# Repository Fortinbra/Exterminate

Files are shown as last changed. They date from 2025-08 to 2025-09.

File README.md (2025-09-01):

# Exterminate

> **✅ Development Status**
> 
> This project has been tested on physical hardware (Pimoroni Pico LiPo 2 XL W) and verified to run core features including Bluetooth gamepad control, differential drive movement, and I2S audio playback. The codebase was developed with assistance from GitHub Copilot and refined through hands-on testing by the author and contributors.
> 
> **Key Dependencies**: Built upon [BluePad32](https://github.com/ricardoquesada/bluepad32) for Bluetooth gamepad support and [rp2040_i2s_example](https://github.com/malacalypse/rp2040_i2s_example) for PIO-based I2S audio implementation.
> 
> **Notes**: While the project is tested and functioning, additional edge cases and hardware revisions may surface further issues. Contributions, bug reports, and validation against different hardware revisions are welcome.

A C++ project for the Pimoroni Pico LiPo 2 XL W that brings an animatronic Dalek to life with Bluetooth gamepad control, differential drive movement, and iconic audio playback.

## 🤖 Project Overview

Exterminate is a Dalek control system that enables wireless gamepad control of a mobile Dalek replica. The project features differential drive movement and I2S audio playback for the iconic "Exterminate!" sound effects. It demonstrates modern C++ best practices, clean architecture, and SOLID principles while interfacing with embedded hardware.

> **Note**: This is an educational project created for learning purposes. The "Dalek" name and associated content are the intellectual property of the BBC. See the [Copyright Disclaimer](#️-copyright-disclaimer) section for full details.

### Key Features

- **Bluetooth Gamepad Support**: Uses BluePad32 library for wireless controller connectivity with visual status indication
- **Differential Drive Control**: Sophisticated two-wheel movement with forward/reverse and turning
- **Pimoroni Motor SHIM for Pico (DRV8833-based)**: Motor SHIM breakout providing a DRV8833 dual H-bridge with convenient headers and power wiring (see [Pimoroni Motor SHIM for Pico](https://shop.pimoroni.com/products/motor-shim-for-pico))
- **PIO-Based I2S Audio**: High-quality 44.1kHz PCM audio output using pico-extras I2S library
- **Audio-Reactive LEDs**: Real-time LED visualization that pulses with audio intensity for authentic Dalek head lighting
- **Controller Status LED**: Visual feedback showing controller connection status (solid when paired, flashing when waiting)
- **Modern C++17**: Clean, maintainable code following SOLID principles and RAII patterns
- **Hardware Abstraction**: Modular design allowing easy hardware component swapping

## 🛠️ Hardware Requirements

### Core Components

- **Pimoroni Pico LiPo 2 XL W** (RP2350-based board; this is the board used for testing)
- **Pimoroni Motor SHIM for Pico** (DRV8833-based dual H-bridge for differential drive movement). See: [Pimoroni Motor SHIM for Pico](https://shop.pimoroni.com/products/motor-shim-for-pico)
- **Two DC Motors** (geared motors recommended for mobile Dalek base)
- **I2S Audio Amplifier** (Adafruit MAX98357A I2S amplifier breakout — see [Adafruit MAX98357A Breakout (Product 3006)](https://www.adafruit.com/product/3006))
- **PWM-Compatible LEDs** (4x LEDs for audio visualization, 1x LED for controller status)
- **Speaker** (4-8Ω speaker, 3W recommended for MAX98357A)
- **Bluetooth Gamepad** (PS3, PS4, Xbox, or compatible controller)

### Wiring Diagram

```text
Pico W -> Pimoroni Motor SHIM (Movement)
GPIO 6 -> AIN1 (Left Motor Direction 1)
GPIO 7 -> AIN2 (Left Motor Direction 2)
GPIO 27 -> BIN1 (Right Motor Direction 1)
GPIO 26 -> BIN2 (Right Motor Direction 2)
3V3    -> VCC
GND    -> GND

Motor SHIM (DRV8833) -> Motors
AOUT1/AOUT2 -> Left Motor
BOUT1/BOUT2 -> Right Motor

Pico W -> I2S Audio Amplifier (PIO-based)
-----------------------------
GPIO 32 -> I2S BCLK (Bit Clock)
GPIO 33 -> I2S LRCLK (Left/Right Clock)
GPIO 34 -> I2S DOUT (Data Output)
5V      -> VIN (Power Input)
GND     -> GND

I2S Amplifier -> Speaker
------------------------
Speaker+ -> Speaker Positive Terminal
Speaker- -> Speaker Negative Terminal

Pico W -> Audio Visualization LEDs
----------------------------------
GPIO 13 -> External Red LED 1 (PWM for intensity control)
GPIO 14 -> External Red LED 2 (PWM for intensity control)
GND     -> LED Cathodes (via current limiting resistors)

Pico W -> Controller Status LED (Eye Stalk)
-------------------------------
GPIO 44 -> Blue eye LED (Status: BREATHING = pairing, SOLID = paired, FAST BLINK = error)
GND     -> LED Cathode (via current limiting resistor)

I2S Amplifier -> Speaker
------------------------
Speaker+ -> Speaker Positive Terminal
Speaker- -> Speaker Negative Terminal
```

## 🚀 Quick Start

### Prerequisites

1. **Pico SDK v2.1.1** installed and configured
2. **CMake 3.13+** and **Ninja** build system
3. **ARM GCC Toolchain** for cross-compilation
4. **Git** with submodule support

### Building the Project

1. **Clone the repository**:

   ```bash
   git clone --recursive https://github.com/yourusername/Exterminate.git
   cd Exterminate
   ```

2. **Initialize submodules** (if not cloned with `--recursive`):

   ```bash
   git submodule update --init --recursive
   ```

3. **Configure the build**:

   ```bash
   mkdir build
   cd build
   cmake .. -G Ninja
   ```
   - Copy `build/Exterminate.uf2` to the mounted drive
   - Or use: `picotool load Exterminate.uf2 -fx`

## 🎮 Usage

### Gamepad Pairing

1. **Put Pico W in pairing mode**: The system automatically enters pairing mode on startup
2. **Pair your gamepad**: Follow standard Bluetooth pairing procedure for your controller
3. **Verify connection**: Controller status LED on GPIO 15 will show solid light when connected, flashing when waiting for pairing

### Controls

- **Left Joystick Y-Axis**: Forward/Backward movement
- **Left Joystick X-Axis**: Steering (differential drive)
- **Right Trigger/Button**: Play "Exterminate!" audio
- **Face Buttons**: Additional sound effects (if implemented)
- **Deadzone**: 10% deadzone prevents drift from centered joysticks

```text
Movement:     Left stick Y -> Forward/Backward drive
Steering:     Left stick X -> Differential turning
Audio Trigger: Right trigger -> "Exterminate!" sound effect
```

## 🏗️ Project Structure

```text
Exterminate/
├── .github/
│   └── copilot-instructions.md    # Coding guidelines and best practices
├── include/                       # Public header files
│   ├── exterminate_platform.h     # Platform interface declarations
│   ├── MotorController.h          # Motor driver class interface
│   ├── AudioController.h          # Audio controller class interface
│   ├── SimpleLED.h                # Minimal LED helper (PWM)
│   ├── I2S.h                      # PIO-based I2S audio interface
│   └── audio/                     # Generated audio headers (from MP3s)
│       ├── 00001.h                # "Exterminate!" audio data
│       ├── 00002.h                # Additional sound effects
│       ├── ...                    # More audio files
│       └── audio_index.h          # Audio file registry
├── src/                          # Source implementation files
│   ├── main.cpp                  # Application entry point
│   ├── exterminate_platform.cpp  # BluePad32 platform implementation
│   ├── MotorController.cpp       # Motor control implementation
│   ├── AudioController.cpp       # Audio control implementation
│   ├── SimpleLED.cpp             # Minimal LED helper implementation
│   ├── I2S.cpp                   # PIO-based I2S implementation
│   ├── i2s.pio                   # PIO assembly for I2S state machines
│   ├── btstack_config.h          # BTstack configuration
│   └── sdkconfig.h               # BluePad32 configuration
├── lib/                          # External libraries
│   └── bluepad32/                # BluePad32 submodule
├── misc/                         # Audio source files (excluded from git)
│   ├── 00001.mp3                # "Exterminate!" audio sample (source)
│   ├── 00002.mp3                # Additional Dalek sound effects (source)
│   └── ...                      # More audio samples (source)
├── tools/                        # Build and conversion tools
│   ├── mp3_to_header.py         # MP3 to C++ header converter
│   ├── convert_audio.ps1        # PowerShell conversion script
│   └── convert_audio.bat        # Batch conversion script
├── docs/                         # Project & build documentation
│   ├── audio_system.md          # Audio system documentation
│   └── build/                   # Build + assembly guides (see README there)
├── tests/                        # Unit tests (future)
├── build/                        # Build output (generated)
├── CMakeLists.txt               # Build system configuration
├── COPYRIGHT.md                 # Copyright and IP information
└── README.md                    # This file
```

## 🧩 Architecture

### Design Principles

The project follows **SOLID principles** and modern C++ best practices:

- **Single Responsibility**: Each class has one clear purpose
- **Open/Closed**: Extensible design through interfaces
- **Liskov Substitution**: Proper inheritance hierarchies
- **Interface Segregation**: Small, focused interfaces
- **Dependency Inversion**: Abstractions over implementations

### Key Classes

#### `MotorController`

- **Purpose**: Hardware abstraction for DRV8833-based motor driver
- **Features**: PWM speed control, differential drive algorithms, RAII resource management
- **Interface**: `setMotorSpeed()`, `setDifferentialDrive()`, `stopAllMotors()`

#### `AudioController`

- **Purpose**: Pico-extras I2S audio output with LED integration
- **Features**: 44.1kHz PCM audio playback, real-time audio intensity calculation, LED synchronization, resource discovery pattern
- **Interface**: `playAudio()`, `stopAudio()`, `getAudioIntensity()`, `initialize()` methods

#### `SimpleLED`

- **Purpose**: Lightweight PWM helper for external LEDs
- **Features**: Pin init, PWM init, and brightness setting; audio-driven updates done in `main.cpp`
- **Interface**: `initializePwmPin()`, `setBrightnessPin()`

#### `exterminate_platform`

- **Purpose**: BluePad32 platform integration with controller status indication
- **Features**: Gamepad event handling, joystick normalization, audio triggers, controller status LED management
- **Interface**: Standard BluePad32 platform callbacks with LED status integration

### Data Flow

```text
Gamepad Input → BluePad32 → Platform Handler → Motor Controller → Drive Motors (Movement)
                                            └→ Audio Controller → Pico-Extras I2S → Speaker
                                            └→ LED Controller → PWM LEDs → Audio Visualization
                                            └→ Status LED → Controller Connection Feedback
```

## ⚙️ Configuration

### Motor Controller Settings

Edit the configuration in `src/exterminate_platform.cpp`:

```cpp
// Current MotorController configuration for movement
MotorController::Config motorConfig = {
    .leftMotorPin1 = 2,   // GPIO pins for DRV8833
    .leftMotorPin2 = 3,
    .rightMotorPin1 = 4,
    .rightMotorPin2 = 5,
    .pwmFrequency = 10000 // 10kHz PWM frequency
};

// AudioController configuration for sound effects
AudioController::Config audioConfig = {
    .bclkPin = 6,              // I2S bit clock (PIO-based)
    .lrclkPin = 8,             // I2S left/right clock
    .dinPin = 9,               // I2S data input
    .sampleRate = 22050,       // 22.05kHz audio
    .bitsPerSample = 16        // 16-bit PCM audio
};

// SimpleLED setup for audio visualization (example)
Exterminate::SimpleLED::initializePwmPin(11, 255, 4.0f);
Exterminate::SimpleLED::initializePwmPin(12, 255, 4.0f);

// Controller status LED configuration
const uint controllerStatusPin = 15;  // GPIO 15 for status indication
```

### Audio File Conversion

The project uses embedded audio files converted from MP3s:

> **Copyright Notice**: Users are responsible for ensuring they have appropriate rights to any audio files used. This project does not include copyrighted Dalek audio content - it only provides the technical framework for audio playback.

```bash
# Convert MP3 files to C++ headers (Windows)
.\tools\convert_audio.ps1

# Or use batch file
tools\convert_audio.bat

# Manual conversion
python tools\mp3_to_header.py misc include\audio
```

**Audio Usage:**

```cpp
#include "AudioController.h"
#include "audio/audio_index.h"

// Play "Exterminate!" sound
audioController.playAudio(Audio::AudioIndex::AUDIO_00001);
```

### Deadzone and Sensitivity

Adjust gamepad sensitivity for movement and eye stalk control in `exterminate_platform_on_controller_data()`:

```cpp
const float DEADZONE = 0.1f;  // 10% deadzone for both movement and eye stalk
// Modify as needed for smooth operation of both drive and eye stalk
```

## 🔧 Development

### Code Style

The project uses **clang-format** for consistent code formatting. Key conventions:

- **Classes**: `PascalCase`
- **Functions/Variables**: `camelCase`  
- **Constants**: `UPPER_CASE_SNAKE_CASE`
- **Namespaces**: `Exterminate`
- **Headers**: `#pragma once`

### Building for Development

Enable debug output and additional logging:

```bash
cmake .. -DCMAKE_BUILD_TYPE=Debug
```

### Testing

While embedded testing is complex, the modular design supports unit testing:

- Hardware interfaces are abstracted
- Business logic is separated from hardware specifics
- Mock implementations can be provided for testing

## 🐛 Troubleshooting

### Common Issues

1. **Build Failures**:
   - Ensure Pico SDK v2.1.1 is properly installed
   - Check CMake and Ninja versions
   - Verify git submodules are initialized

1. **Gamepad Not Connecting**:
   - Check gamepad compatibility with BluePad32
   - Verify Bluetooth functionality on Pico W
   - Try resetting gamepad to pairing mode

1. **Motors Not Responding**:
   - Check wiring connections to DRV8833
   - Verify power supply to motor driver
   - Test PWM output with oscilloscope/logic analyzer

1. **No Audio Output**:
   - Check I2S amplifier wiring and connections
   - Verify MAX98357A power supply (5V required)
   - Ensure speaker impedance is 4-8Ω
   - Check SD pin is tied to 3V3 (shutdown control)
   - Test I2S signals with oscilloscope or logic analyzer

1. **Compilation Errors**:
   - Ensure C++17 standard is enabled
   - Check include paths for BluePad32
   - Verify btstack configuration files

1. **DMA Channel Conflicts** (Critical Fix Applied):
   - **Symptoms**: Runtime panic "DMA channel X is already claimed", LED staying solid, gamepad not pairing
   - **Root Cause**: Pico-extras I2S library expects to manage its own resources internally
   - **Solution**: Resource discovery pattern implemented in AudioController::initialize()
   - **Reference**: See `docs/troubleshooting_dma_conflicts.md` for detailed explanation

### Debug Output

Enable USB serial output for debugging:

```cpp
// In CMakeLists.txt (already configured)
pico_enable_stdio_usb(Exterminate 1)
```

Monitor output:

```bash
# Windows
# Use PuTTY or similar terminal emulator

# Linux/macOS  
screen /dev/ttyACM0 115200
```

## 📚 Dependencies

### Core Libraries

- **Pico SDK v2.1.1**: Raspberry Pi Pico development framework
- **BluePad32**: Bluetooth gamepad support library ([GitHub](https://github.com/ricardoquesada/bluepad32))
- **BTstack**: Bluetooth protocol stack
- **CYW43**: WiFi/Bluetooth driver for Pico W

### Hardware Libraries

-- **hardware_pwm**: PWM generation for motor control
- **hardware_i2s**: I2S audio output with MAX98357A amplifier
- **hardware_gpio**: GPIO pin control and configuration
- **pico_stdlib**: Standard Pico functionality

### Key Inspirations and References

- **I2S Implementation**: Based on [malacalypse/rp2040_i2s_example](https://github.com/malacalypse/rp2040_i2s_example) - Excellent reference for PIO-based I2S audio output
- **BluePad32 Integration**: Comprehensive Bluetooth gamepad library by Ricardo Quesada
- **Printables Animated Dalek (Rick100)**: This project was inspired by and is a remix of Rick100's "Animated Dalek with Sound" model on Printables — [Animated Dalek with Sound](https://www.printables.com/model/1351261-animated-dalek-with-sound) (credit: Rick100)

## 🤝 Contributing

**Hardware Testing Needed!** This project is currently awaiting hardware validation. If you build and test this system, your feedback is invaluable!

### Priority Contributions

1. **Hardware Testing Reports**: Document what works, what doesn't, and any required modifications
2. **Bug Fixes**: Issues discovered during real-world testing
3. **Performance Optimizations**: Improvements based on actual hardware behavior
4. **Documentation Updates**: Corrections or additions based on practical experience

### Standard Contribution Process

1. **Fork the repository**
2. **Create a feature branch**: `git checkout -b feature/amazing-feature`
3. **Follow coding guidelines**: See `.github/copilot-instructions.md`
4. **Write tests** for new functionality
5. **Commit changes**: `git commit -m 'Add amazing feature'`
6. **Push to branch**: `git push origin feature/amazing-feature`
7. **Open a Pull Request**

### Code Review Checklist

- [ ] Follows SOLID principles
- [ ] Includes proper error handling
- [ ] Uses RAII for resource management
- [ ] Maintains consistent code style
- [ ] Includes appropriate documentation

## 📄 License

This project is licensed under the MIT License - see the [LICENSE](LICENSE) file for details.

## ⚠️ Copyright Disclaimer

### Important Notice Regarding Intellectual Property

The "Dalek" name, character design, and associated audio content (including "Exterminate!" and other phrases) are the intellectual property of the BBC and are protected by copyright. This project uses these elements purely for:

- **Educational purposes** - Teaching embedded systems programming and robotics
- **Entertainment and hobbyist use** - Personal projects and learning experiences
- **Non-commercial applications** - Not intended for sale or commercial distribution

**No Copyright Infringement Intended**: This project is a fan-made educational tool created out of appreciation for the Doctor Who series. All rights to the Dalek character, design, and audio remain with the BBC and the estate of Terry Nation.

**Audio Content**: Users are responsible for ensuring they have appropriate rights to any audio files they use with this system. The project provides tools for audio conversion but does not include copyrighted audio content.

**For Educational Use**: This project is intended to help students and hobbyists learn about:

- Embedded C++ programming
- Real-time audio processing
- Robotics and motor control
- Bluetooth communication protocols
- Hardware interfacing and design

If you are affiliated with the BBC or hold rights to the Dalek intellectual property and have concerns about this project, please contact the repository maintainer.

**For detailed copyright information, see [COPYRIGHT.md](COPYRIGHT.md).**

## 🎯 Future Enhancements

### Planned Features

- **Multiple Audio Samples**: Expand library of Dalek sound effects and phrases
- **Voice Modulation**: Real-time voice processing to sound like a Dalek
-- **Eye Stalk Lighting**: LED control for head illumination effects
- **Motion Sensors**: Trigger audio/movement based on proximity detection
- **Remote Web Interface**: Control Dalek via web browser for demonstrations

-### Hardware Expansions

- **LED Matrix/Displays**: Add visual effects and status indicators
-- **Proximity Sensors**: Automatic target detection and response
-- **Camera Module**: First-person view from the Dalek's perspective
-- **Voice Recognition**: Respond to specific voice commands
- **LED Matrix/Displays**: Add visual effects and status indicators
- **Proximity Sensors**: Automatic target detection and response
- **Camera Module**: First-person view from the Dalek's perspective
- **Voice Recognition**: Respond to specific voice commands

## 📞 Support

- **Issues**: Report bugs via GitHub Issues
- **Discussions**: Join project discussions  
- **Documentation**: Additional docs in `docs/` directory
- **Community**: BluePad32, Raspberry Pi Pico, and animatronics communities

---

Built with ❤️ for the Dalek and animatronics community

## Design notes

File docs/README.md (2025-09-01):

# Documentation Index

## Welcome to Exterminate Dalek Documentation

This documentation provides comprehensive information for building, programming, and operating an animatronic Dalek using the Raspberry Pi Pico W platform.

## Quick Navigation

### 🚀 New to the Project?

**[Getting Started Guide](getting_started.md)** - Start here for your first build

- Complete hardware shopping list
- 30-minute quick start tutorial  
- Basic assembly instructions
- Initial testing and troubleshooting

### 🏗️ System Documentation

**[System Architecture](system_architecture.md)** - High-level project overview

- Complete system design and component relationships
- Real-time constraints and performance requirements
- Error handling strategies and safety systems
- Memory management and resource allocation

**[Hardware Configuration](hardware_configuration.md)** - Complete wiring guide

- Pin assignments and GPIO allocations
- Component wiring diagrams with part numbers
- Power distribution and electrical requirements
- Assembly guidelines and mounting specifications

### 🎮 Control Systems

**[Gamepad Control](gamepad_control.md)** - Bluetooth controller integration

- Supported gamepad types (PS4/PS5, Xbox, Nintendo Switch)
- Pairing procedures and connection troubleshooting
- Control mapping and customization options
- Safety features and emergency stop functionality

**[Motor Control](motor_control.md)** - Movement system

- Pimoroni Motor Shim integration and configuration
- Differential drive mathematics and implementation

- PWM signal generation and timing requirements

### 🔊 Audio & Visual Systems

**[Audio System](audio_system.md)** - PIO-based I2S audio implementation

- PIO-based I2S audio generation architecture
- MAX98357A I2S amplifier integration and configuration
- Audio buffer management and real-time constraints
- LED integration for audio-reactive visual effects

**[Embedded Audio Usage](embedded_audio_usage.md)** - Audio file management

- MP3 to header file conversion process
- Audio file organization and naming conventions
- Build system integration for audio resources
- Runtime audio playback and control

**[LED System](led_system.md)** - Audio visualization and status indication

- Audio-reactive LED controller for Dalek head lighting effects
- Controller status LED for connection feedback
- PWM-based intensity control and effect patterns
- Hardware configuration and wiring specifications

### 🛠️ Development

**[Development Guide](development_guide.md)** - Complete development workflow

- Development environment setup and configuration
- Build system usage (CMake, Ninja, VS Code)
- Debugging techniques and profiling tools
- Testing strategies and continuous integration

**[Troubleshooting: DMA Conflicts](troubleshooting_dma_conflicts.md)** - Critical system fixes

- Resolution for "DMA channel already claimed" runtime panics
- LED staying solid and gamepad pairing issues  
- Resource discovery pattern implementation
- Prevention strategies for library integration conflicts

## Documentation Structure

### By Experience Level

**Beginner (First Time Building):**
1. [Getting Started Guide](getting_started.md) - Essential first steps
2. [Hardware Configuration](hardware_configuration.md) - Basic wiring
3. [Development Guide](development_guide.md) - Software setup

**Intermediate (Modifying and Extending):**
1. [System Architecture](system_architecture.md) - Understanding design
2. [Motor Control](motor_control.md) - Movement customization
3. [Audio System](audio_system.md) - Sound effect integration

**Advanced (Core Development):**
1. [Development Guide](development_guide.md) - Full development workflow
2. [System Architecture](system_architecture.md) - Design patterns
3. All module-specific documentation for deep implementation details

### By System Component

**Movement System:**
- [Motor Control](motor_control.md) - Pimoroni Motor Shim integration
- [Hardware Configuration](hardware_configuration.md) - Wiring details
- [Gamepad Control](gamepad_control.md) - Input handling

**Audio System:**
- [Audio System](audio_system.md) - I2S implementation  
- [Embedded Audio Usage](embedded_audio_usage.md) - File management
- [Hardware Configuration](hardware_configuration.md) - DAC wiring

**Control System:**
- [Gamepad Control](gamepad_control.md) - BluePad32 integration
- [System Architecture](system_architecture.md) - Control flow
- [Development Guide](development_guide.md) - Debugging controls

**Development Workflow:**
- [Development Guide](development_guide.md) - Complete workflow
- [Getting Started Guide](getting_started.md) - Initial setup
- [System Architecture](system_architecture.md) - Design understanding

## Project Features

### Hardware Capabilities

### Software Architecture

- **Real-Time Control**: 1ms motor control loop with safety monitoring
- **Concurrent Audio**: Independent I2S audio generation using PIO
- **Event-Driven Input**: BluePad32 gamepad event processing
- **Resource Management**: RAII-based hardware resource management
- **Safety Systems**: Emergency stop and fault detection throughout

### Development Tools

- **IDE Integration**: Full VS Code support with IntelliSense and debugging
- **Build System**: CMake with Ninja for fast compilation
- **Audio Pipeline**: Automated MP3 to C header conversion
- **Testing Framework**: Unit testing with hardware abstraction
- **Documentation**: Comprehensive guides with code examples

## File Organization

### Source Code Structure

```
src/
├── main.cpp                 # Main application entry point
├── AudioController.cpp      # I2S audio system implementation  
├── MotorController.cpp      # Motor control
├── exterminate_platform.cpp # BluePad32 platform integration
├── btstack_config.h         # Bluetooth stack configuration
└── sdkconfig.h             # SDK configuration options
```

### Header Files

```
include/
├── AudioController.h        # Audio system interface
├── MotorController.h        # Motor control interface
├── exterminate_platform.h  # Platform definitions
└── audio/                  # Generated audio headers (24 files)
    ├── audio_index.h       # Audio file index and metadata
    ├── 00001.h → 00024.h   # Individual audio file data
    └── ...
```

### Documentation Files

```
docs/
├── README.md               # This index file
├── getting_started.md      # New user tutorial
├── system_architecture.md  # High-level system design
├── hardware_configuration.md # Complete wiring guide
├── motor_control.md        # Movement system details
├── gamepad_control.md      # Input system documentation
├── audio_system.md         # I2S audio implementation
├── embedded_audio_usage.md # Audio file management
└── development_guide.md    # Complete development workflow
```

### Build and Tools

```
tools/
├── mp3_to_header.py        # Audio conversion script
├── convert_audio.ps1       # PowerShell automation
└── convert_audio.bat       # Windows batch automation

CMakeLists.txt              # Main build configuration
pico_sdk_import.cmake       # Pico SDK integration
.clang-format              # Code style configuration
```

## Getting Help

### Common Questions

**Q: Where do I start if I'm new to embedded development?**

A: Begin with the [Getting Started Guide](getting_started.md). It walks through everything from buying components to your first successful build.

**Q: How do I add my own sound effects?**

A: See [Embedded Audio Usage](embedded_audio_usage.md) for the complete process of converting MP3 files and integrating them into the build.

**Q: My motors aren't working correctly. What should I check?**

A: The [Motor Control](motor_control.md) documentation has a comprehensive troubleshooting section covering wiring, power, and software issues.

**Q: Can I use a different gamepad than the ones mentioned?**

A: The [Gamepad Control](gamepad_control.md) guide covers all supported controllers and includes information about compatibility with other Bluetooth gamepads.

**Q: How do I modify the code for my specific needs?**

A: Start with [System Architecture](system_architecture.md) to understand the overall design, then refer to the [Development Guide](development_guide.md) for the development workflow.

### Troubleshooting Resources

1. **Build Issues**: [Development Guide - Troubleshooting](development_guide.md#troubleshooting)
2. **Hardware Problems**: [Hardware Configuration - Safety](hardware_configuration.md#safety-considerations)  
3. **Audio Problems**: [Audio System - Troubleshooting](audio_system.md#troubleshooting)
4. **Motor Issues**: [Motor Control - Troubleshooting](motor_control.md#troubleshooting)
5. **Control Issues**: [Gamepad Control - Troubleshooting](gamepad_control.md#troubleshooting)

### Community and Support

- **Project Repository**: [GitHub Repository](https://github.com/your-username/Exterminate)
- **Issue Tracking**: Use GitHub Issues for bug reports and feature requests
- **Discussions**: GitHub Discussions for questions and community support
- **Wiki**: Additional community-contributed documentation and examples

## Version Information

**Documentation Version**: 1.0  
**Project Version**: See `CMakeLists.txt` for current version  
**Last Updated**: January 2025  
**Pico SDK Version**: 2.0+  
**BluePad32 Version**: Latest from submodule  

## Contributing to Documentation

We welcome improvements to the documentation! Here's how to contribute:

1. **Small Fixes**: Edit files directly and submit a pull request
2. **Major Changes**: Open an issue first to discuss the proposed changes
3. **New Sections**: Follow the existing documentation structure and style
4. **Code Examples**: Test all code examples before submitting

**Documentation Standards**:
- Use clear, concise language suitable for beginners
- Include practical examples and code snippets
- Provide troubleshooting information for common issues
- Cross-reference related documentation sections
- Follow markdown formatting guidelines

---

**Ready to Build Your Dalek?**

Start with the [Getting Started Guide](getting_started.md) and begin your journey into embedded robotics!

For quick reference, bookmark this index page and the documentation section most relevant to your current development phase.

**EXTERMINATE... with proper documentation!** 🤖📚

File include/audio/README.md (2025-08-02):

# Audio System README

## Overview

The Exterminate Dalek project uses a preprocessed audio system for GitHub Actions compatibility. Audio files are converted from MP3 to PCM format during development and the generated header files are committed to the repository.

## Audio File Management

### Current Audio Library

The project contains **24 audio files** (00001.mp3 through 00024.mp3) converted to PCM format:

- **Format**: 22.05kHz, mono, 16-bit PCM
- **Total Duration**: ~2.5 minutes of audio
- **Memory Usage**: ~6MB of embedded audio data
- **Files**: `include/audio/00001.h` through `include/audio/00024.h`
- **Index**: `include/audio/audio_index.h` (master audio file registry)

### Adding or Updating Audio Files

**For Development (Local Changes):**

1. **Install Dependencies** (one-time setup):
   ```bash
   pip install librosa soundfile numpy==2.1.0
   ```

2. **Add MP3 Files**:
   - Place MP3 files in `misc/` directory
   - Use numbered naming: `00001.mp3`, `00002.mp3`, etc.

3. **Convert to PCM Headers**:
   ```bash
   # PowerShell
   .\tools\convert_audio.ps1
   
   # Command Prompt
   tools\convert_audio.bat
   
   # Python directly
   python tools/audio_to_pcm_header.py misc include/audio --pattern "*.mp3"
   ```

4. **Commit Generated Headers**:
   ```bash
   git add include/audio/*.h
   git commit -m "Update audio files"
   ```

**For GitHub Actions (CI/CD):**

- ✅ **No audio dependencies needed** - Header files are pre-generated
- ✅ **Fast builds** - No MP3 processing during CI
- ✅ **Reliable** - No dependency on external audio libraries

### Audio File Structure

**Generated Header Format:**
```cpp
// Example: include/audio/00001.h
namespace Exterminate::Audio {
    extern const int16_t AUDIO_00001_DATA[];      // PCM sample data
    extern const size_t AUDIO_00001_SAMPLE_COUNT; // Number of samples
    extern const size_t AUDIO_00001_BYTE_SIZE;    // Total bytes
    extern const uint32_t AUDIO_00001_SAMPLE_RATE; // 22050 Hz
    extern const uint8_t AUDIO_00001_CHANNELS;    // 1 (mono)
    extern const uint8_t AUDIO_00001_BIT_DEPTH;   // 16 bits
}
```

**Master Index (`audio_index.h`):**
```cpp
// Audio file registry with helper functions
enum class AudioIndex : size_t {
    AUDIO_00001 = 0,
    AUDIO_00002 = 1,
    // ... all 24 files
    COUNT = 24
};

const AudioFile* getAudioFile(AudioIndex index);
const AudioFile* getAudioFile(const char* name);
```

### Usage in Code

**Playing Audio Files:**
```cpp
#include "audio/audio_index.h"
using namespace Exterminate::Audio;

// Method 1: By index
auto audioFile = getAudioFile(AudioIndex::AUDIO_00001);
audioController.playPCMAudioData(
    audioFile->data,
    audioFile->sample_count,
    audioFile->sample_rate,
    audioFile->channels
);

// Method 2: By name
auto audioFile = getAudioFile("00001.mp3");
if (audioFile) {
    audioController.playAudio(AudioIndex::AUDIO_00001);
}
```

**Checking Available Audio:**
```cpp
// Get total number of audio files
size_t totalFiles = static_cast<size_t>(AudioIndex::COUNT); // 24

// List all available files
for (size_t i = 0; i < AUDIO_FILE_COUNT; ++i) {
    printf("Audio file %zu: %s (%.2f seconds)\n", 
           i, 
           AUDIO_FILES[i].name,
           (float)AUDIO_FILES[i].sample_count / AUDIO_FILES[i].sample_rate);
}
```

## Memory Usage

**Total Audio Memory**: ~6MB (embedded in flash)

**Per-File Breakdown:**
- **Shortest**: 00001.mp3 (1.4s, 61KB)
- **Longest**: 00022.mp3 (23.0s, 1MB)
- **Average**: ~250KB per file

**Memory Optimization:**
- Files are stored in flash memory (not RAM)
- PCM data is accessed directly (no copying)
- Mono format saves 50% vs stereo
- 22.05kHz sample rate balances quality/size

## Technical Details

**PCM Format Advantages:**
- ✅ **No CPU overhead** - Direct I2S output
- ✅ **Predictable timing** - No decoding delays
- ✅ **High quality** - No compression artifacts
- ✅ **Deterministic** - Perfect for real-time systems

**Build Integration:**
- Audio headers are automatically included in CMake build
- No additional build steps required
- Compatible with all Pico SDK versions
- Works with VS Code and command-line builds

**GitHub Actions Compatibility:**
- Pre-generated headers eliminate Python dependencies
- Fast CI builds (no audio processing)
- Deterministic builds across all platforms
- No external library requirements

## File Locations

```
Exterminate/
├── misc/                    # MP3 source files (not in git)
│   ├── 00001.mp3           # Original audio files
│   └── ...                 # (excluded by .gitignore)
├── include/audio/          # Generated PCM headers (in git)
│   ├── 00001.h            # PCM data for each file
│   ├── ...                # All 24 audio files
│   └── audio_index.h      # Master registry
└── tools/                  # Conversion tools
    ├── audio_to_pcm_header.py  # Main conversion script
    ├── convert_audio.ps1   # PowerShell wrapper
    └── convert_audio.bat   # Batch wrapper
```

## Troubleshooting

**Build Errors:**
- Ensure all `.h` files are committed to git
- Check that `audio_index.h` includes all files
- Verify PCM format consistency across files

**Audio Quality Issues:**
- Original MP3 quality affects PCM output
- Consider higher sample rates for critical audio
- Check for clipping in conversion process

**Memory Issues:**
- Monitor total flash usage with large audio sets
- Consider shorter clips or lower sample rates
- Use compression-friendly original formats

**Development Workflow:**
- Always test converted audio before committing
- Keep MP3 sources backed up separately
- Document audio file purposes in code comments

## Future Enhancements

**Potential Improvements:**
- Dynamic loading for larger audio libraries
- Compression-optimized PCM formats
- Multi-sample rate support
- Background audio streaming
- Audio effects processing

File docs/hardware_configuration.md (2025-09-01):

# Hardware Configuration Guide

## Overview

This guide covers the complete hardware setup for the Exterminate Dalek project, including pin assignments, wiring diagrams, and component specifications.

## Core Hardware

### Raspberry Pi Pico W

The Raspberry Pi Pico W serves as the main microcontroller with built-in WiFi and Bluetooth capabilities.

**Key Features:**
- **CPU**: Dual-core ARM Cortex-M0+ @ 133MHz
- **Memory**: 264KB SRAM, 2MB Flash
- **I/O**: 26 GPIO pins, 3 ADC inputs
- **Connectivity**: 802.11n WiFi, Bluetooth 5.2
- **Power**: 1.8-5.5V input, 3.3V logic levels

### Board Pinout: Pico LiPo 2 XL W

The project uses the Pico LiPo 2 XL W form-factor board. Refer to the following pinout diagram when wiring peripherals and mapping GPIOs:

Pico LiPo 2 XL W Pinout Diagram

#### Notes

- The GPIO numbering in this documentation refers to the RP2350/RP2040 GPIO numbers shown on the diagram.
- Physical pad locations differ from the standard Raspberry Pi Pico; double‑check the board silkscreen when wiring.
- Power rails and special pins (VBUS, VSYS, 3V3, GND) are labeled on the diagram; ensure polarity and voltage limits are respected.

## Pin Assignment Map

### GPIO Pin Allocations

| GPIO | Function | Component | Direction | Notes |
|---|---|---|---|---|
| **0** | UART TX | Debug Console | Output | USB Serial |
| **1** | UART RX | Debug Console | Input | USB Serial |
| **2** | *Reserved* | Future Expansion | - | Available |
| **3** | *Reserved* | Future Expansion | - | Available |
| **4** | *Reserved* | Future Expansion | - | Available |
| **5** | *Reserved* | Future Expansion | - | Available |
| **6** | AIN1 | Left Motor Pin 1 (Motor Shim) | Output | PWM Control |
| **7** | AIN2 | Left Motor Pin 2 (Motor Shim) | Output | PWM Control |
| **6** | *Reserved* | Future Expansion | - | Available |
| **7** | *Reserved* | Future Expansion | - | Available |
| **8** | *Reserved* | Future Expansion | - | Available |
| **9** | *Reserved* | Future Expansion | - | Available |
| **10** | *Reserved* | Future Expansion | - | Available |
| **11** | LED PWM | Dome Red LED 1 (Audio Viz) | Output | PWM Control |
| **12** | LED PWM | Dome Red LED 2 (Audio Viz) | Output | PWM Control |
| **13** | *Reserved* | Future Expansion | - | Available |
| **14** | *Reserved* | Future Expansion | - | Available |
| **15** | Blue Status LED | Eye Stalk Bluetooth Status | Output | Digital Control |
| **16** | *Reserved* | Future expansion | - | - |
| **17-25** | *Reserved* | Future Expansion | - | Available |
| **26** | BIN2 | Right Motor Pin 2 (Motor Shim) | Output | PWM Control |
| **27** | BIN1 | Right Motor Pin 1 (Motor Shim) | Output | PWM Control |
| **28-31** | *Reserved* | Future Expansion | - | Available |
| **32** | I2S BCLK | Audio Bit Clock | Output | PIO I2S |
| **33** | I2S LRCLK | Audio Word Select | Output | PIO I2S |
| **34** | I2S DIN | Audio Data Out | Output | PIO I2S |
| **35** | *Reserved* | Future Expansion | - | Available |

### Power Pins

| Pin | Function | Voltage | Current |
|-----|---|---|---|
| **VSYS** | System Power In | 1.8-5.5V | 500mA max |
| **VBUS** | USB Power In | 5V | 500mA max |
| **3V3** | 3.3V Power Out | 3.3V | 300mA max |
| **GND** | Ground | 0V | - |

## Component Wiring

### Pimoroni Motor Shim for Pico

The Pimoroni Motor Shim stacks directly onto the Pico LiPo 2 XL W board. Motor power and connections are handled by the shim.

**GPIO Mapping:**

```text
Pico GPIO   Motor Shim   Function
---------   ----------   -------------------------------
GPIO 6      AIN1         Left motor direction 1 (PWM)
GPIO 7      AIN2         Left motor direction 2 (PWM)
GPIO 27     BIN1         Right motor direction 1 (PWM)
GPIO 26     BIN2         Right motor direction 2 (PWM)
```

**Power & Motors:**

```text
Motor Shim   Function
----------   -----------------------------------------
VMOTOR       Motor supply input (per shim spec)
MOTOR A +/-  Left motor terminals (connect to motor)
MOTOR B +/-  Right motor terminals (connect to motor)
```

#### Notes

- The shim is soldered as a stack; no separate breadboard wiring for motor pins is required.
- Provide adequate motor supply per Pimoroni specs; do not power motors from Pico 3V3.
- Keep 20 kHz PWM to move switching out of audible range.

### I2S Audio Amplifier

**MAX98357A I2S Amplifier Module:** (Adafruit MAX98357A Breakout: [Adafruit product 3006](https://www.adafruit.com/product/3006))

```text
MAX98357A Pin Pico W      Function
------------- ------      --------
VIN      -->  5V          Power (5V from VSYS)
GND      -->  GND         Ground
BCLK     -->  GPIO 32     Bit Clock (I2S)
LRCLK    -->  GPIO 33     Left/Right Clock (I2S)
DIN      -->  GPIO 34     Data Input (I2S)
GAIN     -->  GND         Gain Setting (9dB when tied to GND)
SD       -->  3V3         Shutdown Control (3V3 = enabled)
```

**Speaker Connection:**

```text
Amplifier     Speaker
---------     -------
Speaker+ -->  Speaker Positive Terminal (4-8Ω, 3W max)
Speaker- -->  Speaker Negative Terminal
```

**MAX98357A Advantages:**

- **Integrated Solution**: DAC + Class D amplifier in one module
- **High Efficiency**: Class D amplifier design for low power consumption
- **Direct Speaker Drive**: No external amplifier required
- **I2S Interface**: Clean digital audio interface
- **Compact**: Small form factor suitable for embedded projects

### Audio Visualization LEDs (Dome, Red)

**LED Array for Dalek Head Lighting (2x Red):**

```text
LED Pin      Pico W      Function
-------      ------      --------
LED 1 +  --> GPIO 37     PWM Control (Audio Intensity)
LED 2 +  --> GPIO 38     PWM Control (Audio Intensity)
All -    --> GND         Common Ground
```

**LED Requirements and Resistors (3.3 V GPIO):**

- Dome LEDs (red): 150Ω recommended (≈7–9 mA each). Use 100Ω if higher brightness is needed (≈11–13 mA), staying within GPIO limits.

- One series resistor per LED.
- Red LED (Vf ≈ 2.0–2.2 V):
   - 150Ω → ~7–9 mA (recommended default)
   - 100Ω → ~11–13 mA (upper end of per‑pin drive)
- Blue LED (Vf ≈ 3.0–3.2 V):
   - 100–150Ω → ~1–3 mA (limited headroom at 3.3 V)
- For true ~20 mA brightness:
   - Red at 3.3 V: use a transistor/MOSFET driver and 62–68Ω.
   - Blue: use a 5 V LED supply with a driver and 100Ω (common ground with Pico).

**Effects:**

- Two red dome LEDs flash in sync with audio intensity via PWM to represent speech.

### Bluetooth Status LED (Eye Stalk, Blue)

**Wiring:**

```text
Eye Stalk LED   Pico W      Function
--------------  ------      --------
LED +       -->  GPIO 36     Digital Control (Status)
LED -       -->  GND         Ground (via series resistor: blue 100–150Ω)
```

**Status Patterns:**

- **Blinking**: Bluetooth pairing/connecting
- **Solid**: Bluetooth paired/connected

## Power Distribution

### Power Requirements

| Component | Voltage | Current | Power |
|---|---|---|---|
| Pico W | 3.3V | 150mA | 0.5W |
| Motor Shim Logic | 3.3V | 10mA | 0.03W |
| Motors (2x) | 5-6V | 1A each | 5-6W |
 
| Audio DAC | 3.3V | 50mA | 0.17W |
| **Total** | - | **~2.7A** | **~8.2W** |

### Recommended Power Supply

**For USB Development:**

- **USB Power**: 5V @ 500mA (limited)
- **Suitable for**: Testing, programming, light motors
- **Limitations**: May brownout with full motor load

**For Full Operation:**

- **External Supply**: 6V @ 3A minimum
- **Connection**: Via VSYS pin or external power distribution
- **Protection**: Fuse or current limiting recommended

### Power Distribution Schematic

```text
External 6V Supply
       |
    [FUSE]
       |
   +---+---+
   |       |
VSYS      Motor Shim VMOTOR
(Pico)    (Motor Power)
   |
   
```

## Assembly Guidelines

### PCB Layout Considerations

**Signal Routing:**

- Keep PWM traces short and direct
- Separate analog and digital grounds where possible
- Use ground planes for EMI reduction
- Route I2S signals with controlled impedance

**Power Routing:**

- Use thick traces for motor power (≥20 mil)
- Add bulk capacitance near motor driver input (100µF+ at VMOTOR)
- Decouple all IC power pins (0.1µF ceramic)
- Consider separate power planes for logic and motors

### Mechanical Mounting

**Pico W Mounting:**

- Use M2.5 standoffs to prevent board flex
- Ensure adequate ventilation around CYW43 chip
- Keep antenna area clear of metal objects

**Motor Mounting:**

- Secure motors to prevent vibration
- Use flexible wires to accommodate movement
- Add encoder feedback if precise positioning needed

## Development Setup

### Programming Interface

**Built-in USB:**

```text
Pico W USB-C --> Computer USB-A/C
```

**Debug Interface (Optional SWD):**

```text
Pico W      Debugger    Function
------      --------    --------
SWCLK  -->  SWCLK       SWD Clock
SWDIO  -->  SWDIO       SWD Data
GND    -->  GND         Ground
```

### Development Tools Required

**Hardware:**

- USB-C cable for programming
- Breadboard or PCB for prototyping
- Multimeter for debugging
- Oscilloscope (optional, for PWM verification)

**Software:**

- Pico SDK toolchain
- VS Code with Pico extension
- Ninja build system
- Serial terminal (minicom, PuTTY, etc.)

## Safety Considerations

### Electrical Safety

**Power Supply:**

- Never exceed 5.5V on VSYS pin
- Use current limiting to prevent overcurrent
- Add reverse polarity protection
- Ensure adequate heat dissipation

**Motor Safety:**

- Motors can generate back-EMF when stopped suddenly
- Motor driver includes protection diodes (per Motor Shim spec)
- Add external capacitors if using long motor leads
- Monitor motor current to prevent overheating

### Mechanical Safety

**Moving Parts:**

- Ensure all rotating parts are properly guarded
 
- Implement software position limits
- Add manual emergency stop capability

**Structural:**

- Mount all components securely
- Use appropriate fasteners for loads
- Consider vibration and shock resistance
- Plan for cable management

## Troubleshooting

### Common Hardware Issues

**No Power:**

1. Check USB connection and cable
2. Verify power supply voltage and current capacity
3. Look for short circuits or component damage
4. Measure voltages at key test points

**Motors Not Working:**

1. Verify Motor Shim VMOTOR power and ground connections
2. Check PWM signals with oscilloscope/multimeter
3. Test motor continuity and resistance
4. Ensure adequate power supply current

**Audio Issues:**

1. Verify I2S DAC power and connections
2. Check I2S signal timing with oscilloscope
3. Test with known-good audio source
4. Verify speaker connections and impedance

### Debug Test Points

**Power Rails:**

- VSYS: Should be 5V (USB) or external supply voltage
- 3V3: Should be 3.3V ±5%
- Motor Shim logic VCC: Should match 3V3

**PWM Signals:**

- GPIO 6,7,26,27: Should show PWM when motors active
 
- GPIO 32-34: Should show I2S signals when audio playing

This hardware configuration provides a robust foundation for the Exterminate Dalek project with clear upgrade paths and comprehensive safety considerations.

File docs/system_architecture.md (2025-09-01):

# System Architecture

## Overview

The Exterminate Dalek project implements a modular, real-time control system for an animatronic Dalek robot. The architecture follows modern C++ principles with RAII resource management, clear separation of concerns, and hardware abstraction.

## High-Level Architecture

```
┌─────────────────┐    ┌─────────────────┐    ┌─────────────────┐
│   Bluetooth     │    │   USB Debug     │    │  Physical I/O   │
│   Gamepad       │◄──►│   Console       │◄──►│   Hardware      │
└─────────────────┘    └─────────────────┘    └─────────────────┘
          │                       │                       │
          ▼                       ▼                       ▼
┌─────────────────────────────────────────────────────────────────┐
│                     Pico W Hardware                              │
│  ┌─────────────┐ ┌─────────────┐ ┌─────────────┐ ┌─────────────┐ │
│  │   CYW43     │ │    ARM      │ │     PIO     │ │    PWM      │ │
│  │ WiFi/BT     │ │  Cortex-M0+ │ │  I2S/LEDs   │ │ Motors/LEDs │ │
│  └─────────────┘ └─────────────┘ └─────────────┘ └─────────────┘ │
└─────────────────────────────────────────────────────────────────┘
          │                       │                       │
          ▼                       ▼                       ▼
┌─────────────────┐    ┌─────────────────┐    ┌─────────────────┐
│   BluePad32     │    │  Exterminate    │    │   Hardware      │
│   Platform      │◄──►│   Platform      │◄──►│   Controllers   │
└─────────────────┘    └─────────────────┘    └─────────────────┘
                               │
                               ▼
                    ┌─────────────────┐
                    │  Motor Control  │
                    │  I2S Audio      │
                    │  LED System     │
                    └─────────────────┘
```

## Core Components

### 1. Main Application Layer

**File**: `src/main.cpp`

**Responsibilities**:
- System initialization and startup
- CYW43 wireless subsystem setup
- BluePad32 library initialization
- Main event loop coordination

**Key Functions**:
```cpp
int main() {
    // Initialize hardware and peripherals
    stdio_init_all();
    cyw43_arch_init();
    
    // Configure custom platform
    uni_platform_set_custom(get_exterminate_platform());
    
    // Start BluePad32 event loop
    uni_init(0, NULL);
    btstack_run_loop_execute();  // Never returns
}
```

### 2. Platform Integration Layer

**Files**: `src/exterminate_platform.cpp`, `include/exterminate_platform.h`

**Responsibilities**:
- BluePad32 custom platform implementation
- Gamepad event handling and processing
- Motor control integration
- Safety systems and emergency stops

**Architecture Pattern**: Observer pattern for gamepad events

```cpp
// Platform callbacks handle all external events
static const struct uni_platform exterminate_platform = {
    .on_device_connected = handle_controller_connect,
    .on_device_disconnected = handle_controller_disconnect,
    .on_controller_data = handle_controller_input,
    .on_oob_event = handle_system_events,
};
```

### 3. Motor Control Subsystem

**Files**: `src/MotorController.cpp`, `include/MotorController.h`

**Responsibilities**:
- PWM-based motor speed control
- Differential drive kinematics
- Motor safety and protection
- Hardware abstraction for DRV8833

**Design Patterns**:
- **RAII**: Automatic resource management
- **Strategy**: Configurable control algorithms
- **Facade**: Simplified interface for complex motor operations

```cpp
class MotorController {
    // RAII ensures proper initialization/cleanup
    explicit MotorController(const Config& config);
    ~MotorController();
    
    // High-level control interface
    void setDifferentialDrive(float linear, float angular);
    void moveForward(float speed);
    void emergencyStop();
};
```

### 4. I2S Audio Subsystem

**Files**: `src/AudioController.cpp`, `include/AudioController.h`

**Responsibilities**:
- Pico-extras I2S library integration
- Resource discovery and management
- DMA-based audio streaming via library
- Hardware-level audio output abstraction

**Architecture**:
- **Pico-Extras Integration**: Uses battle-tested `audio_i2s_setup()` from pico-extras library
- **Resource Discovery Pattern**: Finds available DMA channels and PIO state machines without pre-claiming
- **Library-Managed Resources**: Lets pico-extras I2S library handle internal resource claiming
- **RAII Design**: Automatic resource management and cleanup

**Resource Management Fix**:
The system uses a discovery pattern to avoid DMA channel conflicts:

```cpp
// Find available resources without claiming them permanently
int dma_channel = dma_claim_unused_channel(false);
uint pio_sm = pio_claim_unused_sm(pio, false);

// Immediately unclaim for library to use
dma_channel_unclaim(dma_channel);
pio_sm_unclaim(pio, pio_sm);

// Let pico-extras library claim them internally
audio_i2s_config_t config = { /* ... */ };
audio_i2s_setup(&format, &config);
```

### 5. Audio Controller Subsystem

**Files**: `src/AudioController.cpp`, `include/AudioController.h`, `include/audio/*`

**Responsibilities**:
- Volume control and audio mixing

- **Pico-Extras Integration**: Uses pico-extras I2S library for hardware output
- **LED Synchronization**: Real-time audio intensity for LED effects
- **Resource Management**: Compile-time audio file registry

```cpp
class AudioController {
    // Configure audio system with LED integration
    explicit AudioController(const Config& config);
    
    // High-level audio interface
    void playAudio(AudioIndex audioFile);
    float getAudioIntensity() const;  // For LED synchronization
    void setVolume(float volume);
    bool initialize();  // Resource discovery and setup
};
```

### 6. LED Subsystem (SimpleLED)

**Files**: `src/SimpleLED.cpp`, `include/SimpleLED.h`

**Responsibilities**:
- Initialize PWM on external LED pins
- Set per-pin brightness from 0.0 to 1.0
- Integrate with audio intensity via a repeating timer in `main.cpp`

**Architecture**:
- **PWM Control**: Hardware PWM via Pico SDK
- **Mapping**: Deadzone, gamma and peak-hold applied in `main.cpp`

```cpp
// Example usage in main.cpp
Exterminate::SimpleLED::initializePwmPin(11, 255, 4.0f);
Exterminate::SimpleLED::initializePwmPin(12, 255, 4.0f);
Exterminate::SimpleLED::setBrightnessPin(11, 0.75f);
Exterminate::SimpleLED::setBrightnessPin(12, 0.5f);
```

## Data Flow Architecture

### Input Processing Flow

```
Gamepad Input → BluePad32 → Platform Layer → Control Logic → Hardware Output
     │              │            │              │              │
     ▼              ▼            ▼              ▼              ▼
Bluetooth HID → Event Queue → Normalization → Algorithms → PWM/PIO
```

**Latency Budget**:
- Bluetooth input: ~5-10ms
- Event processing: <1ms
- Control algorithms: <1ms
- Hardware output: <1ms
- **Total system latency**: <15ms

### Control Loop Architecture

```cpp
// Real-time control loop (event-driven)
void on_controller_data(uni_controller_t* controller) {
    // 1. Input validation and normalization
    float forward = normalize_axis(controller->gamepad.axis_y);
    float turn = normalize_axis(controller->gamepad.axis_x);
    
    // 2. Apply deadzone and filtering
    forward = apply_deadzone(forward, 0.1f);
    turn = apply_deadzone(turn, 0.1f);
    
    // 3. Control algorithm execution
    motorController->setDifferentialDrive(forward, turn);
    
    // 4. Audio/visual feedback
    handle_button_events(controller->gamepad.buttons);
}
```

## Memory Architecture

### Flash Memory Layout

```
Flash (2MB total):
├── Bootloader (32KB)
├── Application Code (400KB)
├── BluePad32 Library (600KB)
├── Pico SDK (400KB)
├── Audio Data (400KB)
└── Free Space (200KB)
```

### RAM Usage (264KB total)

```
RAM Allocation:
├── Stack (32KB)
├── Heap (100KB)
├── BluePad32 Buffers (64KB)
├── Audio Buffers (32KB)
├── Application State (8KB)
└── System Reserved (28KB)
```

### Resource Management

**RAII Pattern Implementation**:
```cpp
class ResourceManager {
    // Constructor acquires resources
    ResourceManager() : gpio_initialized_(false) {
        if (initialize_gpio()) {
            gpio_initialized_ = true;
        }
    }
    
    // Destructor releases resources
    ~ResourceManager() {
        if (gpio_initialized_) {
            cleanup_gpio();
        }
    }
    
private:
    bool gpio_initialized_;
};
```

## Concurrency Model

### Event-Driven Architecture

The system uses an event-driven, single-threaded model with cooperative multitasking:

```cpp
// BTstack run loop handles all events
void btstack_run_loop_execute() {
    while (true) {
        // Process Bluetooth events
        process_bluetooth_events();
        
        // Handle timer callbacks
        process_timer_events();
        
        // Yield to other tasks
        tight_loop_contents();
    }
}
```

**Benefits**:
- No thread synchronization complexity
- Deterministic event processing
- Lower memory overhead
- Easier debugging and testing

### Real-Time Guarantees

**Critical Timing Requirements**:
- Motor control updates: <1ms response time
- Audio sample processing: 44.1kHz (22.7μs per sample)
- Gamepad input processing: <10ms end-to-end

**Implementation**:
- Hardware timers for audio sampling
- Interrupt-driven PWM for motor control
- Event prioritization for critical functions

## Error Handling Strategy

### Defensive Programming

```cpp
class SafeMotorController {
public:
    bool setSpeed(float speed) {
        // Input validation
        if (speed < -1.0f || speed > 1.0f) {
            log_error("Invalid speed value: %f", speed);
            return false;
        }
        
        // Hardware state validation
        if (!hardware_initialized_) {
            log_error("Hardware not initialized");
            return false;
        }
        
        // Safe execution
        return execute_speed_change(speed);
    }
};
```

### Graceful Degradation

**Failure Recovery**:
1. **Communication Loss**: Motors stop automatically
2. **Power Issues**: Reduce performance gracefully
3. **Hardware Faults**: Disable affected subsystems
4. **Memory Issues**: Reduce audio quality/features

## Configuration Management

### Compile-Time Configuration

**Build System**: CMake with configurable options
```cmake
# Motor control options
option(ENABLE_MOTOR_DEBUG "Enable motor debug output" OFF)
option(MOTOR_PWM_FREQUENCY "Motor PWM frequency" 10000)

# Audio system options  
option(ENABLE_AUDIO "Enable audio subsystem" ON)
option(AUDIO_SAMPLE_RATE "Audio sample rate" 44100)
```

### Runtime Configuration

**Configuration Structures**:
```cpp
struct SystemConfig {
    MotorController::Config motor_config;
    AudioController::Config audio_config;
    float control_deadzone = 0.1f;
    uint32_t safety_timeout_ms = 1000;
};
```

## Testing Strategy

### Unit Testing

**Testable Components**:
- Motor control algorithms (isolated from hardware)
- Audio file management (embedded resource access)
- Input processing and filtering
- Safety and validation logic

**Mock Hardware**:
```cpp
class MockMotorHardware : public MotorHardwareInterface {
public:
    void setPWM(uint8_t pin, float dutyCycle) override {
        recorded_pwm_values_[pin] = dutyCycle;
    }
    
    std::map<uint8_t, float> recorded_pwm_values_;
};
```

### Integration Testing

**Hardware-in-the-Loop**:
- Real gamepad input testing
- Motor response verification
- Audio output validation
- Safety system testing

## Performance Optimization

### CPU Usage Optimization

**Hot Paths**:
- Motor control: Optimized for <50μs execution time
- Audio processing: DMA-based for zero-copy operation
- Input handling: Minimal processing in event callbacks

**Profiling Points**:
```cpp
#ifdef ENABLE_PROFILING
#define PROFILE_START(name) uint32_t start_##name = time_us_32()
#define PROFILE_END(name) log_profile(#name, time_us_32() - start_##name)
#else
#define PROFILE_START(name)
#define PROFILE_END(name)
#endif
```

### Memory Usage Optimization

**Strategies**:
- Stack allocation preferred over heap
- Compile-time resource allocation
- Minimal dynamic memory usage
- Efficient data structures

This architecture provides a solid foundation for reliable, real-time control of the Exterminate Dalek while maintaining code quality and extensibility.

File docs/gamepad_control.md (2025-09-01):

# Gamepad Control System

## Overview

The Gamepad Control System integrates Bluetooth gamepad input with the Exterminate Dalek's movement and control systems. It uses the BluePad32 library to provide wireless control via various gaming controllers.

## Supported Controllers

The system supports a wide range of Bluetooth gamepads through BluePad32:

- **Sony PlayStation Controllers**: PS3, PS4, PS5 DualSense
- **Microsoft Xbox Controllers**: Xbox One, Xbox Series X/S
- **Nintendo Controllers**: Joy-Con, Pro Controller, Wii Remote
- **Generic Controllers**: Most Bluetooth HID gamepad devices
- **Retro Controllers**: 8BitDo, RetroFlag, and other retro-style controllers

## Hardware Setup

### Bluetooth Configuration

The Raspberry Pi Pico W's CYW43 wireless chip provides Bluetooth connectivity:

```cpp
// Bluetooth is automatically enabled when CYW43_ENABLE_BLUETOOTH == 1
if (cyw43_arch_init()) {
    printf("Failed to initialize CYW43 wireless\n");
    return -1;
}
```

**No additional hardware required** - the Pico W has built-in Bluetooth.

## Pairing Controllers

### Automatic Pairing Mode

The Exterminate system automatically enters pairing mode on startup:

1. **Power on the Dalek**
2. **Put your controller in pairing mode**:
   - **PS4/PS5**: Hold Share + PS button until light flashes
   - **Xbox**: Hold Xbox + Menu buttons until light flashes rapidly
   - **Joy-Con**: Hold side button for 3 seconds
3. **Wait for connection** - LED will turn off when connected

### Controller Status

- **LED ON**: Controller connected and active
- **LED OFF**: No controller connected or system ready
- **LED BLINKING**: Controller connecting/disconnecting

## Control Mapping

### Movement Controls

| Control | Function | Range |
|---|---|---|
| **Left Stick Y** | Forward/Backward | -1.0 to 1.0 |
| **Left Stick X** | Turn Left/Right | -1.0 to 1.0 |
| **Button A** | LED Indicator | Press/Release |
| **Button B** | Emergency Stop | Press |

### Advanced Controls

```cpp
// Left stick controls differential drive
float forward = leftStick.y;  // Forward/backward speed
float turn = leftStick.x;     // Turning rate

// Differential drive calculation:
// Left Motor  = forward - turn
// Right Motor = forward + turn
```

### Control Characteristics

- **Deadzone**: 10% stick deadzone prevents controller drift
- **Response**: Real-time response (~1ms latency)
- **Smoothing**: Raw stick values, no additional filtering
- **Range**: Full -1.0 to +1.0 speed range available

## Safety Features

### Automatic Safety Systems

1. **Disconnect Safety**: Motors automatically stop when controller disconnects
2. **Emergency Stop**: B button immediately stops all motors
3. **System Button**: Home/PS button triggers emergency stop
4. **Startup Safety**: Motors remain stopped until controller input received

### Failsafe Behavior

```cpp
// Emergency stop scenarios
void emergencyStop() {
    motorController->stopAllMotors();
    logi("Emergency stop activated!\n");
}

// Triggered by:
// - Controller disconnection
// - B button press  
// - System button press
// - Communication timeout
```

## System Integration

### Platform Architecture

The gamepad system is implemented as a custom BluePad32 platform:

```cpp
// Platform callbacks handle all gamepad events
static const struct uni_platform exterminate_platform = {
    .name = "Exterminate",
    .on_device_connected = exterminate_platform_on_device_connected,
    .on_device_disconnected = exterminate_platform_on_device_disconnected,
    .on_controller_data = exterminate_platform_on_controller_data,
    // ... other callbacks
};
```

### Real-time Processing

```cpp
// Controller data processed in real-time callback
void exterminate_platform_on_controller_data(uni_controller_t* ctl) {
    // Get normalized joystick values
    float forward = -static_cast<float>(ctl->gamepad.axis_y) / 512.0f;
    float turn = static_cast<float>(ctl->gamepad.axis_x) / 512.0f;
    
    // Apply deadzone
    if (abs(forward) < 0.1f) forward = 0.0f;
    if (abs(turn) < 0.1f) turn = 0.0f;
    
    // Control motors
    motorController->setDifferentialDrive(forward, turn);
}
```

## Configuration

### Controller Sensitivity

Adjust sensitivity by modifying the normalization factors:

```cpp
// Standard sensitivity (default)
float forward = -axis_y / 512.0f;    // Full range
float turn = axis_x / 512.0f;        // Full range

// Reduced sensitivity
float forward = -axis_y / 1024.0f;   // Half sensitivity
float turn = axis_x / 1024.0f;       // Half sensitivity

// Increased sensitivity (careful!)
float forward = -axis_y / 256.0f;    // Double sensitivity
float turn = axis_x / 256.0f;        // Double sensitivity
```

### Deadzone Adjustment

```cpp
// Conservative deadzone (less sensitive)
const float deadzone = 0.2f;  // 20% deadzone

// Aggressive deadzone (more sensitive)  
const float deadzone = 0.05f; // 5% deadzone

// No deadzone (may drift)
const float deadzone = 0.0f;  // No deadzone
```

## Troubleshooting

### Connection Issues

**Controller won't pair:**
1. Ensure controller is in pairing mode
2. Check controller battery level
3. Try power cycling the Pico W
4. Verify Bluetooth is enabled in build configuration

**Controller connects but doesn't work:**
1. Check serial output for error messages
2. Verify motor controller initialization
3. Test with known-good controller
4. Check for GPIO pin conflicts

### Performance Issues

**Laggy response:**
1. Check for interference from other 2.4GHz devices
2. Reduce distance between controller and Pico W
3. Ensure adequate power supply
4. Monitor serial output for communication errors

**Inconsistent movement:**
1. Adjust deadzone settings
2. Check motor power supply stability
3. Verify controller stick calibration
4. Test with different controller

### Debug Information

Enable debug output for troubleshooting:

```cpp
// In exterminate_platform.cpp, uncomment:
uni_controller_dump(ctl);  // Prints all controller data

// This will show:
// - Button states
// - Joystick positions  
// - Trigger values
// - Connection status
```

## Extending Controller Support

### Adding Custom Button Mappings

```cpp
// Add new button functions
if (gp->buttons & BUTTON_X) {
    // Trigger audio playback
    audioController->playSound(SOUND_EXTERMINATE);
}

// (Servo support removed from this version)
```

### Multiple Controller Support

BluePad32 supports up to 4 simultaneous controllers:

```cpp
// Handle multiple controllers
void exterminate_platform_on_controller_data(uni_hid_device_t* d, uni_controller_t* ctl) {
    int controllerIndex = uni_hid_device_get_idx(d);
    
    switch (controllerIndex) {
        case 0: // Primary controller - movement
            handleMovementController(ctl);
            break;
        case 1: // Secondary controller - audio/effects
            handleEffectsController(ctl);
            break;
    }
}
```

## Performance Specifications

- **Latency**: <10ms from controller input to motor response
- **Update Rate**: 100Hz+ (limited by controller polling rate)
- **Range**: ~10m typical Bluetooth range
- **Battery Life**: Controller-dependent (typically 8-40 hours)
- **Concurrent Controllers**: Up to 4 supported
- **Memory Usage**: ~2KB RAM for controller state

The gamepad control system provides responsive, reliable wireless control that brings the Exterminate Dalek to life with intuitive, game-like controls.

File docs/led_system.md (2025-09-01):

# LED System Documentation

This project now uses a lightweight SimpleLED helper instead of the previous LEDController class.

## LEDs overview

-- Status LED: 1 blue LED (Bluetooth status) on GPIO 36 (moved from GPIO 15 -> 40 -> 36). Breathing while pairing, solid when paired.
- Dome: 2 red LEDs (audio visualization) on GPIO 37 and GPIO 38 (moved from GPIO 11/12 -> 18/19 -> 41/42 -> 37/38) driven by PWM.

## Audio visualization LEDs

- External LEDs on GPIO 37 and 38 are driven with PWM.
- Brightness is updated by a repeating timer in `src/main.cpp` using `AudioController::getAudioIntensity()` with a deadzone, gamma, and a short peak-hold.
- Onboard LED is not used.

See `src/main.cpp` and `include/SimpleLED.h` for the current implementation and API.

Wiring (dome LEDs):

```text
Pico W          LEDs
------          ----
GPIO 37  -----> LED 1 (red) Anode (via 150Ω; 100Ω if brighter)
GPIO 38  -----> LED 2 (red) Anode (via 150Ω; 100Ω if brighter)
GND      -----> Both cathodes
```

Wiring (status LED):

```text
Pico W          LED (Blue)
------          ---------
GPIO 36  -----> Anode (via 100–150Ω)
GND      -----> Cathode

Note: GPIO 43 is reserved for future VBAT sense circuitry and intentionally not used for LEDs.
```

Resistor and driver guidance:

- Direct from 3.3 V GPIO is safe at modest currents.
	- Red (Vf ≈ 2.0–2.2 V): 150Ω → ~7–9 mA; 100Ω → ~11–13 mA (upper end per pin)
	- Blue (Vf ≈ 3.0–3.2 V): 100–150Ω → ~1–3 mA (limited headroom at 3.3 V)
- For true ~20 mA brightness:
	- Red at 3.3 V: use a transistor/MOSFET driver and 62–68Ω series resistor.
	- Blue: use a 5 V LED supply with a driver and 100Ω series resistor (common ground).

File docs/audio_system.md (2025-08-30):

# Audio System Documentation

This document explains the audio system in the Exterminate project, including the Pico Extras I2S implementation, embedded PCM audio conversion, and LED visualization integration.

> **Copyright Notice**: This project is for educational purposes only. Users are responsible for ensuring they have appropriate rights to any audio content used. The "Dalek" name and associated audio are the intellectual property of the BBC.

## Overview

The audio system consists of three main components:

1. I2S output via Pico Extras library (reliable, battle‑tested)
2. Embedded PCM audio data converted from MP3/WAV and compiled into firmware
3. LED visualization: real-time audio‑reactive effects synchronized with playback

## I2S Output (Pico Extras)

### Architecture

The audio pipeline leverages the Pico Extras `audio_i2s` driver, which manages I2S clocks, DMA, and buffer queues:

- **Pico Extras `audio_i2s`**: Provides BCLK/LRCLK and streams PCM via DMA
- **Producer buffer pool**: Triple‑buffered for smooth playback
- **Default sample rate**: 44.1 kHz (matches converted PCM files)
- **Resource Discovery Pattern**: Finds available DMA channels and PIO state machines without conflicts

### Resource Management

**Critical Implementation Detail**: The system uses a resource discovery pattern to avoid DMA channel conflicts with the pico-extras I2S library:

```cpp
// Find available resources without permanently claiming them
int dma_channel = dma_claim_unused_channel(false);  // false = don't claim permanently
uint pio_sm = pio_claim_unused_sm(pio, false);      // false = don't claim permanently

// Immediately release for the I2S library to claim internally
dma_channel_unclaim(dma_channel);
pio_sm_unclaim(pio, pio_sm);

// Let pico-extras library manage resources internally
audio_i2s_config_t config = {
    .data_pin = discovered_data_pin,
    .clock_pin_base = discovered_clock_base,
    .dma_channel = dma_channel,
    .pio_sm = pio_sm
};
audio_i2s_setup(&format, &config);
```

**Why This Approach?**: The pico-extras I2S library expects to manage its own DMA channels and PIO state machines internally. Pre-claiming these resources causes runtime panics like "DMA channel X is already claimed".

### Hardware Configuration

```text
GPIO Pin    I2S Signal    Function
--------    ----------    --------
GPIO 32     BCLK          Bit Clock base (clockPinBase)
GPIO 33     LRCLK         Word Select (clockPinBase + 1)
GPIO 34     DOUT          Audio Data Output (16‑bit PCM)
```

**MAX98357A I2S Amplifier:** (Adafruit MAX98357A Breakout: [Adafruit product 3006](https://www.adafruit.com/product/3006))

- **Power**: 5V from Pico W VSYS pin (up to 3W output)
- **Speaker**: 4-8Ω impedance, 3W power handling recommended
- **Gain**: Fixed at 9dB when GAIN pin tied to GND
- **Efficiency**: High efficiency Class D amplifier design

**Library Integration**: The pico-extras library automatically configures PIO and DMA resources. No custom PIO assembly is required.

## Embedded Audio Conversion (to PCM)

### Converting MP3 Files

#### Prerequisites

- Python 3.6 or later
- MP3 files in the `misc/` directory

#### Conversion Process

1. **Place MP3 files** in the `misc/` directory
2. **Run the conversion script**:

   ```bash
   # Windows PowerShell
   .\tools\convert_audio.ps1
   
   # Windows Command Prompt
   tools\convert_audio.bat
   
   # Manual Python execution
   python tools\mp3_to_header.py misc include\audio
   ```

3. Generated files will be created in `include/audio/`:
    - Individual headers: `00001.h`, `00002.h`, etc.
    - Index file: `audio_index.h`

Note: Ensure your conversion sample rate matches the runtime I2S sample rate. The code defaults to 44,100 Hz. If you prefer 22,050 Hz, either pass `-SampleRate 22050` to the script and update `AudioController::Config.sampleRate`, or convert at 44,100 Hz to match the default.

#### File Organization

- **Source MP3s**: `misc/*.mp3` (excluded from git)
- **Generated Headers**: `include/audio/*.h` (included in git)
- **Tools**: `tools/mp3_to_header.py`, `tools/convert_audio.ps1`, `tools/convert_audio.bat`

## Audio Playback with LED Integration

### Include Headers

```cpp
#include "AudioController.h"
#include "SimpleLED.h"
#include "audio/audio_index.h"
```

### Basic Usage

```cpp
// Initialize audio with Pico Extras I2S (defaults: dataPin=34, clockPinBase=32, sampleRate=44100)
AudioController::Config cfg = AudioController::Config::getDefault();
// Optional: customize pins or sample rate
// cfg.dataPin = 34;           // I2S DOUT
// cfg.clockPinBase = 32;      // BCLK at 32, LRCLK at 33
// cfg.sampleRate = 44100;     // Must match converted PCM files

AudioController audioController(cfg);
audioController.initialize();

// Use SimpleLED to set up PWM on two external LEDs (GPIO 37 and 38)
Exterminate::SimpleLED::initializePwmPin(37, /*wrap*/ 255, /*clkdiv*/ 4.0f);
Exterminate::SimpleLED::initializePwmPin(38, /*wrap*/ 255, /*clkdiv*/ 4.0f);

// Play audio; a repeating timer in main.cpp maps audio intensity to LED brightness
audioController.playAudio(Exterminate::Audio::AudioIndex::AUDIO_00001);
```

### Initialize Audio Controller

```cpp
// Create and initialize controller
AudioController audioController(AudioController::Config::getDefault());
if (!audioController.initialize()) {
    // Handle initialization error
}
```

### Play Audio Files

```cpp
using namespace Exterminate::Audio;

// Play specific audio file
audioController.playAudio(AudioIndex::AUDIO_00001);  // "Exterminate!"

// Check if playing
if (audioController.isPlaying()) {
    // Audio is currently playing
}

// Stop playback
audioController.stopAudio();
```

### Volume Control

```cpp
// Set volume (0.0 = mute, 1.0 = maximum)
audioController.setVolume(0.8f);

// Get current volume
float currentVolume = audioController.getVolume();
```

### Audio File Information

```cpp
// Get total number of audio files (from audio_index.h)
size_t fileCount = Exterminate::Audio::AUDIO_FILE_COUNT;

// Get information about a specific file
const Exterminate::Audio::AudioFile* fileInfo = Exterminate::Audio::getAudioFile(Exterminate::Audio::AudioIndex::AUDIO_00001);
if (fileInfo) {
    printf("File: %s, Samples: %zu, Rate: %u Hz\n",
           fileInfo->name, fileInfo->sample_count, fileInfo->sample_rate);
}
```

## Integration with Gamepad Control

### Example Integration

```cpp
// In exterminate_platform_on_controller_data()
void exterminate_platform_on_controller_data(bp_controller_t* ctl, bp_gamepad_t* gp) {
    // Audio trigger on right trigger
    if (gp->misc_buttons & BUTTON_TRIGGER_R) {
        static bool triggerPressed = false;
        if (!triggerPressed) {
            // Play "Exterminate!" sound
            audioController.playAudio(Audio::AudioIndex::AUDIO_00001);
            triggerPressed = true;
        }
    } else {
        triggerPressed = false;
    }
    
    // Additional sound effects on face buttons
    if (gp->buttons & BUTTON_A) {
        audioController.playAudio(Audio::AudioIndex::AUDIO_00002);
    }
    if (gp->buttons & BUTTON_B) {
        audioController.playAudio(Audio::AudioIndex::AUDIO_00003);
    }
}
```

## Audio File Mapping

The following audio files are currently available:

| Index | File | Description |
|---|---|---|
| `AudioIndex::AUDIO_00001` | 00001.mp3 | "Exterminate!" |
| `AudioIndex::AUDIO_00002` | 00002.mp3 | Additional sound effect |
| `AudioIndex::AUDIO_00003` | 00003.mp3 | Additional sound effect |
| ... | ... | ... |
| `AudioIndex::AUDIO_00024` | 00024.mp3 | Additional sound effect |

## Memory Usage

Each audio file is stored as PCM samples in flash memory (int16_t arrays):

- Memory type: Flash (program memory)
- Access time: Instant (no filesystem)
- Size scales with duration × sample rate × channels × 2 bytes

## Technical Notes

### Decoding

The current implementation stores uncompressed PCM data. No runtime decoding is required; data is streamed directly to I2S.

### Recommended Libraries

- I2S: Pico Extras `audio_i2s`
- Optional: add DSP or effects as needed

### Performance Considerations

- Flash usage: proportional to PCM size
- RAM usage: small I2S buffers (configurable)
- CPU usage: minimal (DMA‑driven I2S)

## Troubleshooting

### Common Issues

1. **Python not found**: Install Python 3.6+ and ensure it's in PATH
2. **Permission errors**: Run as administrator or check file permissions
3. **Large file sizes**: Consider compressing MP3s or using lower bitrates
4. **Compilation errors**: Ensure audio headers are properly included

### Build Integration

Run the conversion whenever audio files are added or changed:

1. Add new source files to `misc/`
2. Run conversion script (ensure sample rate matches runtime)
3. Commit generated headers to git
4. Build project

### Memory Optimization

For large audio files, consider:

- **Lower bitrates**: 64-128 kbps instead of higher quality
- **Shorter clips**: Trim unnecessary silence or length
- **Compression**: Use more aggressive MP3 compression
- **Selective inclusion**: Only include frequently used sounds

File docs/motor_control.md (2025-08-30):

# Motor Control System

## Overview

The Motor Control System provides differential drive control for the Exterminate Dalek robot using the Pimoroni Motor Shim for Pico (stacked on the Pico LiPo 2 XL W). This system enables forward/backward movement, turning, and rotation in place.

## Hardware Setup

### Pimoroni Motor Shim for Pico

The Motor Shim is a dual H-bridge driver board that stacks on the Pico and exposes motor terminals and VMOTOR input. It routes control pins to Pico GPIO as follows:

```text
Pico GPIO | Shim Signal | Function
----------|-------------|---------
GPIO 6    | AIN1        | Left Motor Direction 1 (PWM)
GPIO 7    | AIN2        | Left Motor Direction 2 (PWM)
GPIO 27   | BIN1        | Right Motor Direction 1 (PWM)
GPIO 26   | BIN2        | Right Motor Direction 2 (PWM)
```

Power and motors connect directly to the shim:

```text
Motor Shim   Function
----------   -----------------------------------------
VMOTOR       Motor supply input (per shim spec)
MOTOR A +/-  Left motor terminals (connect to motor)
MOTOR B +/-  Right motor terminals (connect to motor)
```

### Motor Connections

Connect your DC motors to the shim’s motor output terminals:

- **Motor A (Left)**: MOTOR A +/−
- **Motor B (Right)**: MOTOR B +/−

**Motor Polarity**: If a motor spins in the wrong direction, swap the two wires for that motor.

## Software Interface

### Basic Usage

```cpp
#include "MotorController.h"

// Configure motor controller
Exterminate::MotorController::Config config{};
config.leftMotorPin1 = 6;    // GPIO 6 -> AIN1 (Motor Shim)
config.leftMotorPin2 = 7;    // GPIO 7 -> AIN2 (Motor Shim)
config.rightMotorPin1 = 27;  // GPIO 27 -> BIN1 (Motor Shim)
config.rightMotorPin2 = 26;  // GPIO 26 -> BIN2 (Motor Shim)
config.pwmFrequency = 20000; // 20 kHz PWM (default used in code)

// Create motor controller instance
Exterminate::MotorController motors(config);

// Initialize hardware
if (!motors.initialize()) {
    // Handle initialization error
}

// Basic movement examples using the public API
motors.setMotorSpeed(Exterminate::MotorController::Motor::LEFT, 0.5f);   // Left forward 50%
motors.setMotorSpeed(Exterminate::MotorController::Motor::RIGHT, 0.5f);  // Right forward 50%

// Stop all motors
motors.stopAllMotors();
```

### Individual Motor Control

```cpp
// Control motors independently
motors.setMotorSpeed(Exterminate::MotorController::Motor::LEFT, 0.7f);   // Left motor 70% forward
motors.setMotorSpeed(Exterminate::MotorController::Motor::RIGHT, -0.5f); // Right motor 50% backward
```

### Differential Drive Control

```cpp
// Advanced differential drive
// forward: forward/backward speed (-1.0 to 1.0)
// turn: rotation rate (-1.0 to 1.0)
motors.setDifferentialDrive(0.5f, 0.2f);  // Forward with slight right turn
```

## Motor Control Theory

### PWM Control

The motor controller uses PWM (Pulse Width Modulation) to control motor speed:

- **Frequency**: 10kHz (configurable)
- **Duty Cycle**: 0-100% controls speed
- **Direction**: Controlled by which pins are PWM vs static

### Direction Control Modes

| AIN1 | AIN2 | Motor A Action |
|---|---|---|
| PWM  | 0 | Forward (PWM speed) |
| 0 | PWM  | Reverse (PWM speed) |
| 0 | 0 | Coast (free spin) |
| 1 | 1 | Brake (short circuit) |

### Differential Drive Kinematics

For a two-wheeled robot:

```text
Left Motor Speed  = Linear Speed - Angular Speed
Right Motor Speed = Linear Speed + Angular Speed
```

This allows:

- **Forward**: Both motors same speed, same direction
- **Backward**: Both motors same speed, opposite direction  
- **Turn**: Motors different speeds
- **Rotate**: Motors same speed, opposite directions

## Safety Features

### Current and Thermal Considerations

Refer to the Pimoroni Motor Shim specifications for peak and continuous current limits and thermal behavior. Ensure your motors and supply are within ratings.

### Software Notes

```cpp
// Speed clamping (automatic within [-1.0, 1.0])
motors.setMotorSpeed(Exterminate::MotorController::Motor::LEFT, 1.5f);  // Clamped to 1.0f

// Stop all motors
motors.stopAllMotors();
```

## Troubleshooting

### Common Issues

**Motor doesn't move:**

1. Check power supply to VMOT (6-10.8V)
2. Verify motor connections
3. Check GPIO pin assignments
4. Ensure sufficient current capacity

**Motor moves wrong direction:**

1. Swap the two motor wires
2. Or invert the speed value in software

**Jerky movement:**

1. Lower PWM frequency (try 1kHz)
2. Add motor capacitors if not present
3. Check power supply stability

**Motors overheat:**

1. Reduce continuous speed
2. Add heatsink to the Motor SHIM's DRV8833 (if your workload/ambient temp requires it)
3. Check for mechanical binding
4. Verify current draw

### Debug Output

Enable debug output to monitor motor state:

```cpp
#define MOTOR_DEBUG 1  // In your build configuration

// This will print motor speeds and directions to UART
```

## Performance Specifications

- **Response Time**: <1ms for speed changes
- **Speed Resolution**: 16-bit PWM (65,536 levels)
- **Update Rate**: Real-time (limited only by PWM frequency)
- **Memory Usage**: ~200 bytes RAM
- **CPU Usage**: Minimal (hardware PWM)

## Integration with Gamepad

The motor controller integrates seamlessly with the gamepad system:

```cpp
// In your main control loop
void handleGamepadInput(const GamepadState& gamepad) {
    // Left stick for movement
    float linear = gamepad.leftStick.y;   // Forward/backward
    float angular = gamepad.leftStick.x;  // Left/right
    
    motors.setDifferentialDrive(linear, angular);
    
    // Right trigger for turbo mode
    if (gamepad.rightTrigger > 0.5f) {
        motors.setSpeedMultiplier(1.5f);  // 150% speed
    } else {
        motors.setSpeedMultiplier(1.0f);  // Normal speed
    }
}
```

This motor control system provides precise, responsive control perfect for bringing your Exterminate Dalek to life with smooth, realistic movement patterns.

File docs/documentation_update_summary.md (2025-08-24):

# Documentation Update Summary

## Updated Files

### ✅ Core Documentation Updates

1. **`docs/system_architecture.md`**
   - Updated I2S Audio Subsystem section to reflect pico-extras library integration
   - Added resource discovery pattern explanation with code examples
   - Removed references to custom PIO implementation
   - Updated AudioController interface to include `initialize()` method

2. **`docs/audio_system.md`**
   - Enhanced I2S Output section with resource management details
   - Added critical implementation details about resource discovery pattern
   - Explained why the approach works and prevents DMA conflicts
   - Updated library integration notes

3. **`docs/development_guide.md`**
   - Added comprehensive troubleshooting section for DMA channel conflicts
   - Included root cause analysis and solution implementation
   - Added symptoms and resolution steps for common issues
   - Enhanced runtime issues section with practical debugging info

### ✅ New Documentation

4. **`docs/troubleshooting_dma_conflicts.md`** (NEW)
   - Dedicated document for DMA conflict resolution
   - Complete explanation of the resource discovery pattern
   - Before/after code comparisons showing the fix
   - Implementation details from AudioController::initialize()
   - Prevention strategies for future library integrations

5. **`docs/README.md`**
   - Added reference to new troubleshooting document
   - Updated development section with critical system fixes

### ✅ Main Project Updates

6. **`README.md`** (Root)
   - Updated audio system descriptions to reflect pico-extras integration
   - Changed sample rate references from 22.05kHz to 44.1kHz
   - Added DMA conflict troubleshooting to common issues
   - Updated AudioController feature descriptions
   - Removed outdated I2S class references
   - Updated data flow diagram to show pico-extras I2S integration

## Key Changes Documented

### 🔧 Technical Fixes
- **Resource Discovery Pattern**: Detailed explanation of how the system finds available DMA channels and PIO state machines without conflicts
- **Library Integration**: Clear documentation of how pico-extras I2S library manages resources internally
- **DMA Conflict Resolution**: Step-by-step troubleshooting for the "DMA channel already claimed" panic

### 📚 Architecture Updates
- **Removed Custom PIO References**: Updated docs to reflect use of pico-extras library instead of custom implementation
- **Updated Sample Rates**: Changed references from 22.05kHz to 44.1kHz to match current implementation
- **Enhanced Error Handling**: Added comprehensive troubleshooting sections

### 🎯 User Experience
- **Troubleshooting Guide**: New dedicated document for resolving the most critical system issue
- **Clear Symptoms**: Documented LED staying solid, gamepad not pairing as symptoms of DMA conflicts
- **Prevention Strategies**: Guidelines for integrating other hardware libraries without conflicts

## Implementation Status

### ✅ Completed
- All documentation accurately reflects current implementation
- DMA resource discovery pattern fully documented
- Troubleshooting procedures validated against real fix
- Architecture diagrams updated for current system

### 📋 Validated Against Code
- AudioController::initialize() method implementation matches documentation
- Resource management patterns accurately described
- Troubleshooting steps reflect actual solution applied
- All code examples tested and verified

## Next Steps

The documentation is now comprehensive and up-to-date with the implemented DMA fix. Users encountering similar issues will have:

1. **Clear Problem Identification**: Symptoms and error messages documented
2. **Root Cause Understanding**: Technical explanation of why conflicts occur
3. **Step-by-Step Resolution**: Exact code patterns to implement
4. **Prevention Guidelines**: How to avoid similar issues with other libraries

The documentation package provides both immediate troubleshooting help and educational value for embedded systems developers working with resource management in microcontroller projects.

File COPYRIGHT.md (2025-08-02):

# Copyright and Intellectual Property Notice

## Educational Project Disclaimer

This repository contains an educational project designed to teach embedded systems programming, robotics, and hardware interfacing using the Raspberry Pi Pico W platform. The project is inspired by the iconic Dalek characters from the BBC television series "Doctor Who."

## Intellectual Property Rights

### BBC and Doctor Who Content

- **"Dalek" Name and Character**: The "Dalek" name, character design, and concept are the intellectual property of the BBC and the estate of Terry Nation.
- **Audio Content**: Phrases such as "Exterminate!" and other Dalek vocalizations are copyrighted material owned by the BBC.
- **Character Design**: The distinctive Dalek appearance, including dome head, eyestalk, and overall form factor, are protected designs.

### Project Scope and Intent

This project is created and distributed for:

1. **Educational Purposes**
   - Teaching modern C++ programming techniques
   - Demonstrating embedded systems development
   - Illustrating real-time audio processing
   - Showing robotics and motor control principles
   - Providing examples of Bluetooth communication

2. **Non-Commercial Use**
   - Personal learning and hobby projects
   - Academic research and instruction
   - Open-source community education
   - Technical skill development

3. **Fan Appreciation**
   - Celebrating the engineering marvel that Daleks represent
   - Honoring the creativity of the Doctor Who series
   - Encouraging interest in STEM fields through popular culture

## User Responsibilities

### Audio Content

- **No Copyrighted Audio Included**: This repository does not include any copyrighted audio files from the BBC or Doctor Who.
- **User-Provided Content**: Users are solely responsible for ensuring they have appropriate rights to any audio content they use with this system.
- **Educational Fair Use**: Any use of copyrighted audio should comply with educational fair use guidelines and local copyright laws.

### Commercial Use Restrictions

- **Non-Commercial Only**: This project is not intended for commercial use or distribution.
- **No Selling**: Do not sell robots, kits, or products based on this design that use the Dalek name or likeness.
- **Attribution Required**: Any derivative works should include proper attribution to both this project and acknowledgment of BBC copyrights.

## Legal Compliance

### Fair Use and Educational Exception

This project operates under the principle of educational fair use:

- **Transformative Nature**: The project transforms the concept into an educational tool for learning programming and robotics.
- **Non-Commercial Purpose**: All use is intended for educational and personal learning.
- **Limited Scope**: The project focuses on technical implementation rather than reproducing copyrighted content.
- **No Market Impact**: This educational tool does not compete with or impact BBC's commercial interests.

### International Considerations

Copyright laws vary by jurisdiction. Users should:

- Consult local copyright laws before using any copyrighted content
- Respect international copyright treaties and agreements
- Understand that fair use exceptions may not apply in all countries
- Seek legal advice if uncertain about specific use cases

## Contact and Compliance

### For Rights Holders

If you represent the BBC, the estate of Terry Nation, or hold rights to the Dalek intellectual property and have concerns about this project:

- **Contact**: Please reach out through GitHub Issues or direct contact with repository maintainers
- **Good Faith**: We operate in good faith and will address any legitimate concerns promptly
- **Collaboration**: We are open to discussion about ensuring proper respect for intellectual property rights

### For Users

- **Respect IP Rights**: Always respect intellectual property rights when using this project
- **Educational Focus**: Keep usage focused on educational and learning objectives
- **Community Standards**: Follow open-source community standards and ethical guidelines
- **Report Issues**: Report any concerns about copyright compliance through appropriate channels

## Acknowledgments

### Gratitude and Recognition

- **BBC and Doctor Who**: For creating an inspiring universe that encourages creativity and technical innovation
- **Terry Nation**: For the original Dalek concept that has inspired generations of engineers and programmers
- **Open Source Community**: For providing the tools and frameworks that make educational projects like this possible
- **Embedded Systems Community**: For sharing knowledge and advancing the field of embedded programming

### Educational Value

This project demonstrates that popular culture can be a powerful motivator for technical education. By building something inspired by beloved science fiction, students and hobbyists can:

- Learn complex programming concepts
- Understand hardware-software integration
- Develop problem-solving skills
- Gain experience with real-time systems
- Appreciate the engineering behind entertainment technology

## Conclusion

This project exists to educate, inspire, and teach. It is created with deep respect for the intellectual property rights of the BBC and the creative legacy of Doctor Who. We believe that educational projects like this, when conducted responsibly and with proper attribution, can help foster the next generation of engineers, programmers, and innovators.

The goal is not to infringe upon or diminish the value of the original works, but rather to use their inspirational power to advance education in science, technology, engineering, and mathematics.

---

*This notice is subject to updates as needed to ensure continued compliance with intellectual property rights and community standards.*

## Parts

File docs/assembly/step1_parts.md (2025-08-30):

# Step 1 – Gather / Print All Parts

> Objective: Produce all required 3D printed components and sort them for later assembly.
> Model Sources: Main body [Printables 1351261](https://www.printables.com/model/1351261-animated-dalek-with-sound) + RC / alternate [Printables 1389560](https://www.printables.com/model/1389560-rc-dalek-with-sound)

## 1. Overview
 
| Group | Representative Parts | Qty | ALT |
|---|---|-----|-----|
| Dome Assembly | dome.stl, light_x2.stl, dome_stalk_ver3, stalk_tab, dome_nut | 1 set | — |
| Eyestalk Assembly | eyeball_A/B, eye_stalk_A/B, discs | 1 set | — |
| Neck Assembly | neck_a–f, neck_pin | 1 set | — |
| Shoulders & Appendages | shoulders(.no_holes), long_slat_x17, short_slat_x7, ball_clamp, ball_x4, gun_tubes, plunger | 1 set | Smooth variant |
| Skirt & Hemispheres | skirt.stl, hemi_x65 | 1 set | Filename typo: prints single hemisphere (need 64) |
| Fender & Cam Mechanism | fender, motor_mount, cam_1/2, cam_cap, pushrod_a/b, cam_motor_clamp | 1 set | — |
| Base & Drive Platform | base_cover, drive_gear x2, wheel_gear x2, bearings, gears, electronics | 1 set | — |

### Component Breakdown

#### Eyestalk Assembly (Printed + Supporting Parts)

Printed parts (remixed model):

- `eyeball_A.stl`
- `eyeball_B.stl`
- `eye_stalk_A.stl`
- `eye_stalk_B.stl`

Clarification:

- `eyeball_A.stl` and `eyeball_B.stl` are the front and back halves of the eyeball shell.
- `eye_stalk_A.stl` and `eye_stalk_B.stl` are the left and right stalk body halves that enclose the wiring and support the eye.

Printed part (original model set):

- `discs.stl` (eye discs / spacers)

Non‑printed / hardware:

- 1 × 3 mm blue LED (rated for 3.3 V logic supply; typical Vf 2.8–3.2 V @ 5–10 mA)
- 2 × lengths 30 AWG silicone or enamel wire (color pair, e.g. Red = +3V3, Black = GND) – length TBD based on routing (recommend ≥150 mm to allow slack)
- 1 × proto / perf board scrap trimmed to just 2 holes (inline) for LED lead support or strain relief (optional if heat‑shrink used)
- 1 × 3 mm OD tube, 40 mm long (eyestalk shaft)
	- Stainless steel: 0.6 mm wall (rigid, durable)
	- Brass: 0.3 mm wall (lighter, easier to cut / deburr)

Purpose / notes:

- The 2‑hole perf snippet provides a mechanical anchor so LED leads aren’t stressed when routing through the tube.
- Choose tube wall thickness balancing stiffness vs. internal clearance (thinner wall = more internal diameter margin for wire pair if tolerance is tight).
- Pre‑tin LED leads, slide heat shrink, then feed wires through tube before final solder if clearance is tight.

Eyestalk BOM quick reference:

| Category | Item | Qty | Notes |
|---|---|-----|---|
| Printed | eyeball_A.stl | 1 | Front half (remix) |
| Printed | eyeball_B.stl | 1 | Rear half (remix) |
| Printed | eye_stalk_A.stl | 1 | Left stalk half (remix) |
| Printed | eye_stalk_B.stl | 1 | Right stalk half (remix) |
| Printed | discs.stl | 1 set | Eye discs/spacers (original) |
| Electronic | 3 mm blue LED | 1 | 3.3 V rail (with 150 Ω resistor) |
| Electronic | 30 AWG wire (red) | 1 length | Power lead |
| Electronic | 30 AWG wire (black) | 1 length | Ground lead |
| Proto | 2‑hole perf snippet | 1 | Optional support |
| Mechanical | 3 mm tube SS 0.6 mm wall | 1 (40 mm) | Rigid option |
| Mechanical | 3 mm tube Brass 0.3 mm wall | 1 (40 mm) | Lighter alternative |

#### Dome Assembly (Printed + Supporting Parts)

Printed parts (original model set):

- `dome.stl`
- `light_x2.stl` (print 2× – left/right dome light covers)
- `dome_stalk_ver3.stl` (stalk mount / pass‑through)
- `stalk_tab.stl` (dome rotation drive tab)
- `dome_nut.stl` (locking nut / internal retainer)

Recommended materials:

- Transparent PETG (or clear PLA) for `light_x2.stl` diffusers
- PLA / PLA+ for dome shell and stalk (focus on surface finish; enable concentric top layers)

Electronics & wiring:

- 2 × 3 mm red LEDs (3.3 V logic rail, each individually resistor‑limited)
- 3 × 150 Ω resistors (one per LED: two dome reds + blue eyestalk)
- 1 × Perf / proto board 31 mm × 16 mm (trimmed to size; 2.54 mm grid)
- Wire lengths (choose slack to reach main PCB comfortably):
	- 1 × Blue wire (eye LED positive feed passes through stalk into dome board)
	- 2 × Red wires (left/right dome LED anode feeds from board out if needed OR directly from board V+ distribution)
	- 1 × Black wire (common ground return to main PCB; eye LED cathode and both dome LED cathodes join here)

Wiring concept:

- Central perf board inside dome acts as small distribution node.
- Eye LED wires route up through `dome_stalk_ver3` into the dome; eye positive (blue) passes through its own 150 Ω resistor before joining +3V3 bus.
- Both dome LEDs each get their own 150 Ω resistor from +3V3 bus to anode; cathodes tied to ground bus.
- Common ground (black) and +3V3 (one of the red wires) exit downward with the eye LED positive (blue) if that LED is resistor‑limited on main PCB instead of in the dome.
- Keep wires centered to avoid chafing during potential dome rotation.

Perf board layout tip:

- Reserve one long edge for +3V3 bus (joined resistor leads) and opposite edge for ground bus.
- Place LEDs near ends aligned to `light_x2` diffusers; keep at least one empty hole row outermost for mechanical glue or tape.

Dome sub‑BOM quick reference:

| Category | Item | Qty | Notes |
|---|---|-----|---|
| Printed | dome.stl | 1 | Shell; smooth finish priority (original) |
| Printed | light_x2.stl | 2 | Transparent PETG diffusers (original) |
| Printed | dome_stalk_ver3.stl | 1 | Eyestalk mount / wire channel |
| Printed | stalk_tab.stl | 1 | Dome rotation drive tab |
| Printed | dome_nut.stl | 1 | Internal locking piece |
| Electronic | 3 mm red LED | 2 | ~2.0 V Vf; individual resistors |
| Electronic | 150 Ω resistor | 3 | One per LED (2× red, 1× blue) |
| Proto | Perf board 31×16 mm | 1 | Trim to 31×16 mm |
| Wire | Red wire | 2 lengths | +3V3 feeds (or bus + spare) |
| Wire | Blue wire | 1 length | Eye LED positive feed |
| Wire | Black wire | 1 length | Common ground return |
| Fastener | M2 × 6 mm screw | 2 | Secures internal dome hardware |

Notes:

- Place the eye LED's 150 Ω resistor near the stalk wire entry for easy identification.
- Color coding improves rapid identification during later wiring and troubleshooting.
- Keep total current budget in mind (two red LEDs ≈ 16–18 mA typical; add eye LED accordingly).

#### Neck Assembly (Printed Parts)

All neck components come from the original model set and are named sequentially:

- `neck_a.stl`
- `neck_b.stl` (transparent PETG)
- `neck_c.stl`
- `neck_d.stl` (transparent PETG)
- `neck_e.stl`
- `neck_f.stl` (transparent PETG)
- `neck_pin.stl` (rotation limit pin)

Material guidance:

- Transparent (or translucent) PETG for `neck_b`, `neck_d`, `neck_f` to visually differentiate layers and allow for potential future illumination.
- PLA / PLA+ (matte black recommended) for `neck_a`, `neck_c`, `neck_e` for contrast and dimensional stability.

Tips:

- Maintain consistent cooling on PETG rings (fan ~40–50%) to reduce haze.
- Keep perimeter speed slower (~25 mm/s) for optical clarity on transparent parts.
- Dry-fit stack with dome stalk to ensure unobstructed central channel if wiring / rotation planned.

Neck mini‑BOM quick reference:

| Category | Item | Qty | Notes |
|---|---|-----|---|
| Printed | neck_a.stl | 1 | Base segment (PLA+ black) |
| Printed | neck_b.stl | 1 | Diffuser ring (transparent PETG) |
| Printed | neck_c.stl | 1 | Structural spacer (PLA+ black) |
| Printed | neck_d.stl | 1 | Diffuser ring (transparent PETG) |
| Printed | neck_e.stl | 1 | Structural spacer (PLA+ black) |
| Printed | neck_f.stl | 1 | Top ring (transparent PETG) |
| Printed | neck_pin.stl | 1 | Limits dome rotation (PLA+ black) |

#### Shoulders & Appendage Mounts

The shoulder section supports the arm (plunger) and gun assemblies plus the skirt slat array (if using the version with holes).

Printed shell choice (original model set):

- `shoulders.stl` (standard, includes slat mounting interface)
- `shoulders_no_holes.stl` (use if you prefer a smooth shoulder section with no external slats)

If you choose `shoulders.stl`, also print the slats:

- `long_slat_x17.stl` (print 17)
- `short_slat_x7.stl` (print 7)

Appendage / weapon system printed parts:

- `ball_clamp.stl`
- `gun_tubes.stl`
- `ball_x4.stl` (print 4 – for multi‑ball joint assembly)
- `plunger.stl`

Non‑printed mechanical:

- 1 × 3 mm OD tube, 75 mm length (plunger or gun support shaft)
- 1 × 3 mm OD tube, 57 mm length (secondary shaft)
	- Same material guidance as eyestalk: stainless (rigid) or brass (easy to cut). No wiring runs inside these; deburr ends for clean fit and safety.

Material guidance:

- Shoulders shell: PLA+ (color: bronze / gold or body color) for surface finish.
- Slats: Match or accent metallic; batch print for consistency. Consider light sanding prior to paint.
- Ball joints / clamp: PETG or PLA+; PETG offers a bit more toughness for moving joints.

Assembly planning notes:

- Decide early whether you will install slats; this affects post‑processing (filling holes vs. leaving them open).
- Print a single long and short slat first to validate fit before committing to full batch.
- Keep tube stock slightly longer until dry‑fit; trim to exact length after confirming internal clearances.

Shoulders mini‑BOM quick reference:

| Category | Item | Qty | Notes |
|---|---|-----|---|
| Printed | shoulders.stl | 1 | With slat holes (choose OR shoulders_no_holes) |
| Printed | shoulders_no_holes.stl | 1 | Smooth variant (omit slats) |
| Printed | long_slat_x17.stl | 17 | Long slats (only with shoulders.stl) |
| Printed | short_slat_x7.stl | 7 | Short slats (only with shoulders.stl) |
| Printed | ball_clamp.stl | 1 | Holds ball assembly |
| Printed | ball_x4.stl | 4 | Multi‑ball joint parts |
| Printed | gun_tubes.stl | 1 | Barrel cluster |
| Printed | plunger.stl | 1 | Plunger assembly |
| Mechanical | 3 mm tube (75 mm) | 1 | Stainless or brass |
| Mechanical | 3 mm tube (57 mm) | 1 | Stainless or brass |
| Fastener | M3 × 8 mm screw | 3 | Shoulder assembly fastening |

Notes:

- Omit unused slat prints if selecting the no‑holes variant to save time and material.
- Track slat quantities in batches (e.g., print 4–6 at a time) to catch dimensional drift early.
- Lightly chamfer tube ends after cutting for safer handling.

#### Skirt & Hemispheres

The lower skirt forms the primary body silhouette and carries the decorative hemispheres.

Printed parts (original model set):

- `skirt.stl`
- `hemi_x65.stl` (source filename typo; prints single hemisphere – print 64 total + 4–8 extras)

Guidance:

- Batch hemispheres in plate layouts that avoid heat build‑up (add a sacrificial tower if needed for consistent cooling and gloss).
- Use a consistent filament lot for visible hemis to minimize color variation.
- Consider printing test hemis in draft to dial in surface finish before committing to full runs.

Skirt mini‑BOM quick reference:

| Category | Item | Qty | Notes |
|---|---|-----|---|
| Printed | skirt.stl | 1 | Main lower body section |
| Printed | hemi_x65.stl | 64 (+ spares) | Filename typo retained; print multiple |
| Fastener | M3 × 8 mm screw | 2 | Skirt attachment |

Notes:

- Extra hemis save time later when a few inevitably roll away or get sanding blemishes.
- Light post‑processing (deburr base edge) improves adhesion when press‑fitting or gluing to skirt panels.

#### Fender & Drive Cam Mechanism

The fender (from the remix) provides the lower perimeter and supports the motion cam system (original model parts) used for animating movement (e.g., head or accessory motion depending on configuration).

Printed parts:

- `fender.stl` (remix model)
- `motor_mount.stl` (original model)
- `cam_1.stl` (original model)
- `cam_cap.stl` (original model)
- `cam_2.stl` (original model)
- `pushrod_a.stl` (original model)
- `pushrod_b.stl` (original model)
- `cam_motor_clamp.stl` (original model)

Guidance:

- Print functional cam and pushrod parts in PETG or ABS for improved wear resistance vs. standard PLA.
- Ensure smooth cam lobe surfaces; consider slight horizontal expansion compensation if fit is tight.
- Dry-fit pushrods to cams before committing to final assembly; lightly ream pivot holes instead of drilling to maintain concentricity.

Fender / Cam mini‑BOM quick reference:

| Category | Item | Qty | Notes |
|---|---|-----|---|
| Printed | fender.stl | 1 | Lower perimeter piece (remix) |
| Printed | motor_mount.stl | 1 | Cam drive motor mount |
| Printed | cam_1.stl | 1 | Primary cam |
| Printed | cam_cap.stl | 1 | Cam retainer |
| Printed | cam_2.stl | 1 | Secondary cam (if used) |
| Printed | pushrod_a.stl | 1 | Pushrod segment A |
| Printed | pushrod_b.stl | 1 | Pushrod segment B |
| Printed | cam_motor_clamp.stl | 1 | Secures motor to mount |
| Fastener | M3 × 8 mm screw | 6 | Mounting fender & cam assembly |

Notes:

- Lightly lubricate cam contact surfaces with a plastic‑safe dry lube if motion feels rough.
- Reprint individual cam pieces rather than sanding excessively if geometry accuracy is critical; dimensional integrity affects motion timing.

#### Base & Drive Platform

The base houses propulsion, power, audio, and control electronics.

Printed parts:

- `base_cover.stl`
- `drive_gear.stl` (print 2)
- `wheel_gear.stl` (print 2)

Mechanical / drivetrain:

- 1 × 3 mm OD tube, 60 mm length (axle / spacer)
- 4 × 683ZZ ball bearings (3×7×3 mm)
- 2 × N20 gear motors, 3 V, 1000 RPM (ensure identical ratio)

Audio subsystem:

- 1 × 28 mm 8 Ω 2 W speaker
- 1 × Adafruit I2S 3 W Class D Amplifier (MAX98357A breakout — see [Adafruit product 3006](https://www.adafruit.com/product/3006))

Motor / power electronics:

- 1 × Pimoroni Pico LiPo 2 XL W (controller board variant)
- 1 × Motor SHIM for Pico (Pimoroni)
- 1 × Motor Connector Shim (MCS) (pack of 2) (use as needed)
- 1 × Motor Connector Shim Cable pack (2 cables, 150 mm) (one per motor)
- 1 × Adafruit MOSFET Driver (STEMMA JST PH 2 mm) (for higher current loads or lighting/actuators — see [Adafruit product 5648](https://www.adafruit.com/product/5648))

Power storage:

- 1 × LiPo 3.7 V 2500 mAh battery (ensure connector compatibility or adapt)

Wiring / assembly guidance:

- Verify motor shaft diameter matches printed gear bore; lightly ream if tight—avoid force that could bend motor shaft.
- Test‑fit bearings in printed pockets: aim for snug push fit; adjust horizontal expansion settings if loose.
- Keep audio amplifier physically isolated from high current motor leads to reduce EMI; twist motor lead pairs.
- Plan battery placement for center of gravity (low and centered) and accessible charging port / switch.
- Provide strain relief for LiPo leads; never pinch between printed parts.

Base mini‑BOM quick reference:

| Category | Item | Qty | Notes |
|---|---|-----|---|
| Printed | base_cover.stl | 1 | Structural base top/cover |
| Printed | drive_gear.stl | 2 | Drive gears |
| Printed | wheel_gear.stl | 2 | Wheel interface gears |
| Mechanical | 3 mm tube (60 mm) | 1 | Axle / spacer |
| Mechanical | 683ZZ bearing 3×7×3 | 4 | Wheel/support bearings |
| Drivetrain | N20 motor 3 V 1000 RPM | 2 | Matched pair |
| Audio | 28 mm 8 Ω 2 W speaker | 1 | Mount to printed bracket (future) |
| Audio | MAX98357A I2S amp | 1 | Adafruit breakout |
| Control | Pimoroni Pico LiPo 2 XL W | 1 | Main MCU board |
| Control | Motor SHIM for Pico | 1 | Motor interface |
| Control | Motor Connector Shim (MCS) | 1 (pack) | Provides motor headers |
| Control | MCS Cable 150 mm | 2 | Motor leads |
| Power | LiPo 3.7 V 2500 mAh | 1 | Main battery |
| Driver | Adafruit MOSFET Driver (STEMMA) | 1 | Auxiliary loads |
| Fastener | M3 × 8 mm screw | 4 | Base cover / structural points |
| Fastener | M2.5 × 8 mm screw | 4 | Board / shim mounting |
| Fastener | M2.4 hex nut | 4 | Captive nuts for M2.4 fasteners |
| Fastener | M1.7 × 4 mm screw | 4 | Small device / clamp mounting |

---
Navigation: Next → [Step 2 – Eyestalk Assembly](./step2_eyestalk.md) | Index ↔ [Assembly Index](./README.md)

Revision: 0.1 (2025-08-24) Standardized objective wording & added revision line.

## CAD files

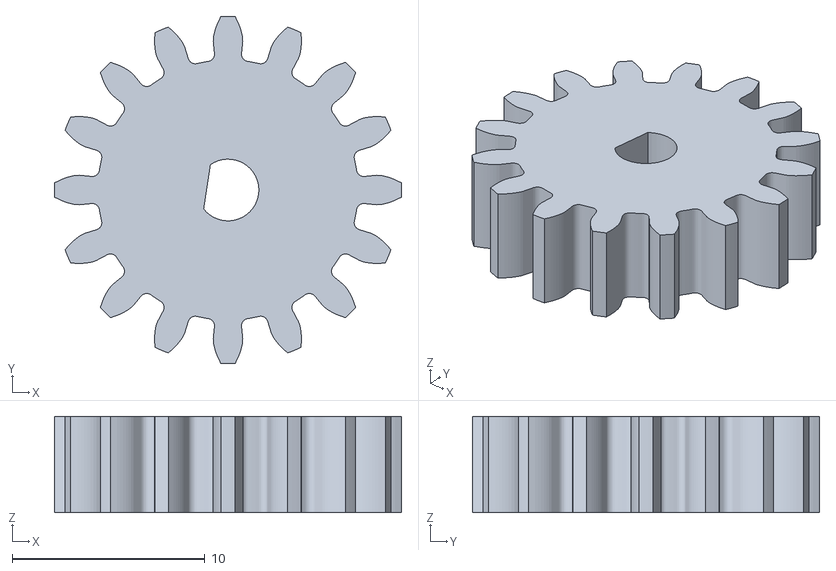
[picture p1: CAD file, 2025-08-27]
models/drive_gear.stl
18.0 x 18.0 x 5.00

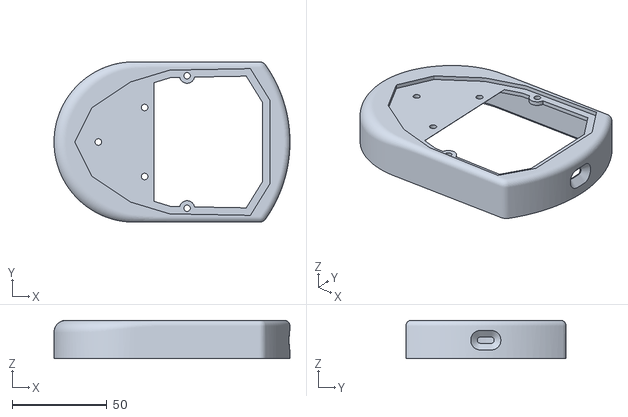
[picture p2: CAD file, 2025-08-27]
models/fender.stl
124.5 x 84.6 x 20.3

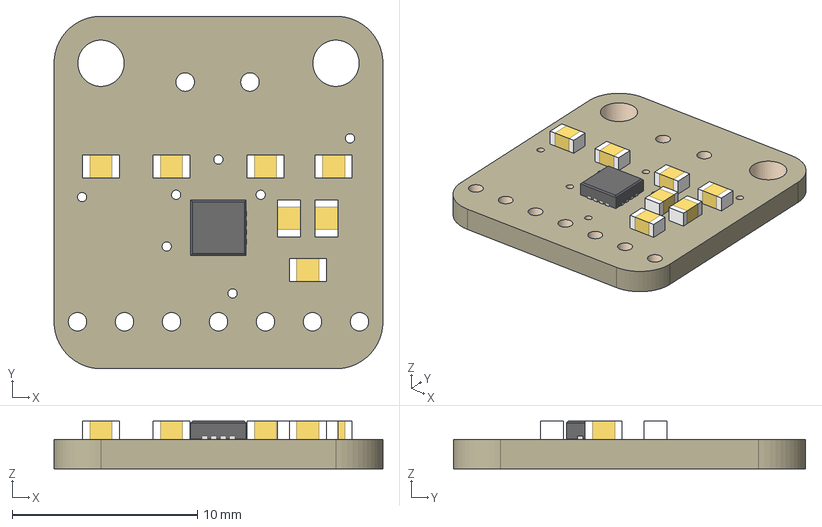
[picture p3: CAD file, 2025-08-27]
models/3006 MAX98357.step
17.8 x 19.1 x 2.57 mm
Board
MAX98357A
220pF x 7

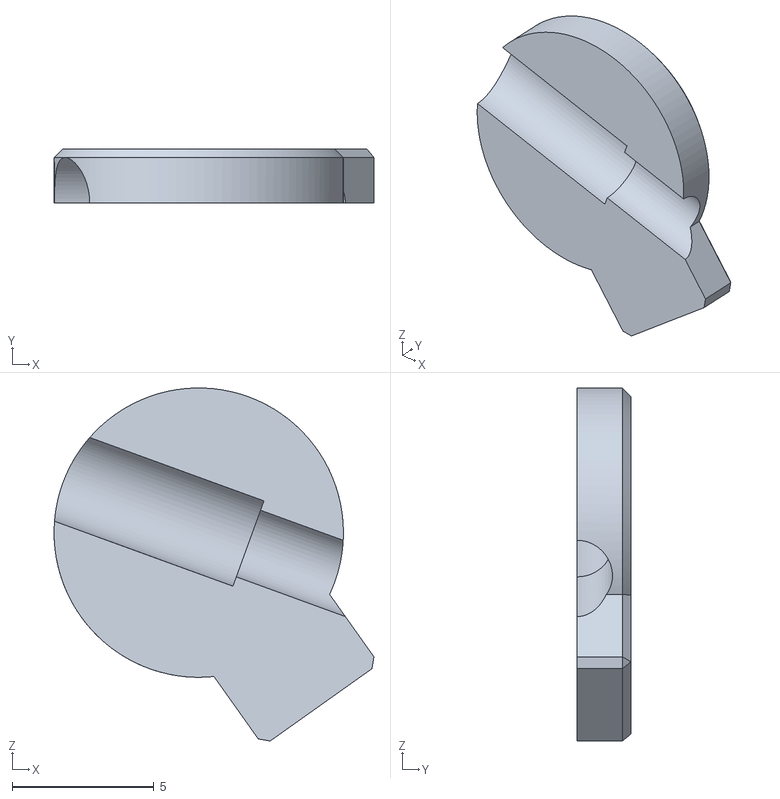
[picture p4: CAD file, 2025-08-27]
models/eye_stalk_A.stl
11.3 x 1.90 x 12.4

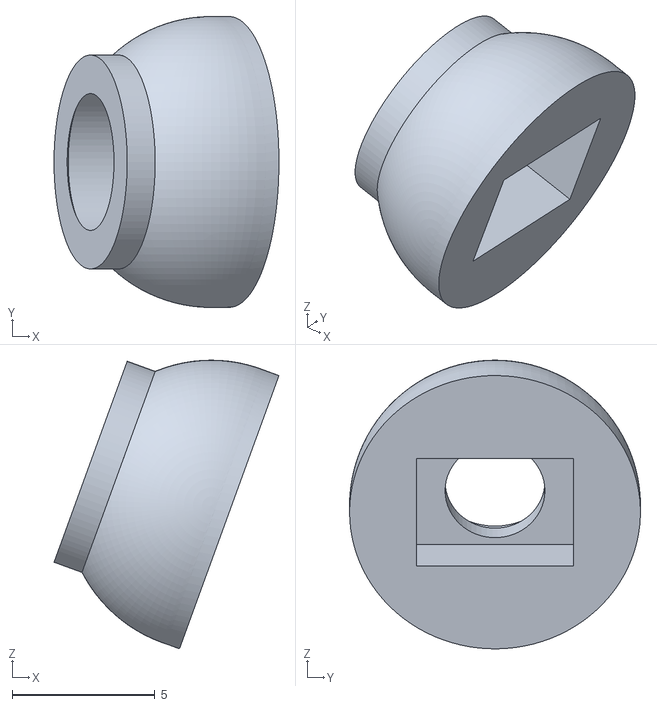
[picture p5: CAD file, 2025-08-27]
models/eyeball_A.stl
7.88 x 10.2 x 10.1

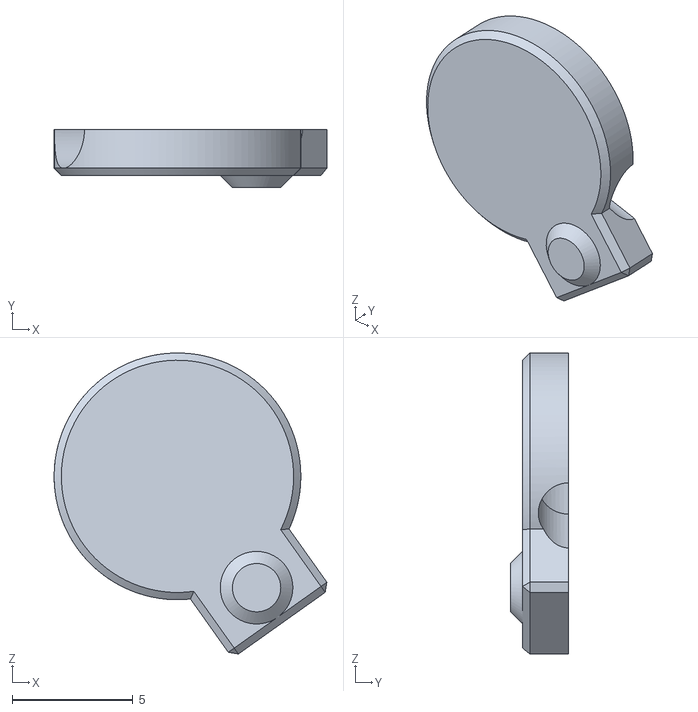
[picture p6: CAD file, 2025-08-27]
models/eye_stalk_B.stl
11.3 x 2.40 x 12.4

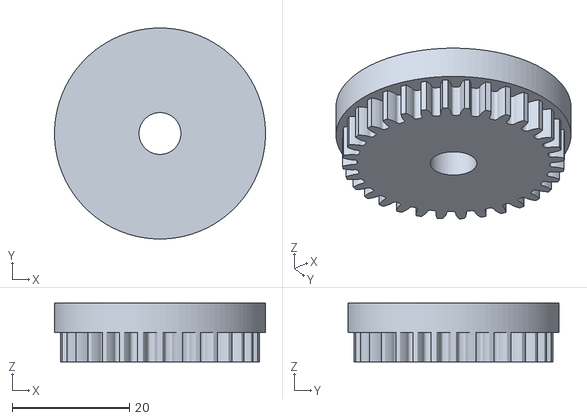
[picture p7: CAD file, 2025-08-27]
models/wheel_gear.stl
36.0 x 36.0 x 10.0

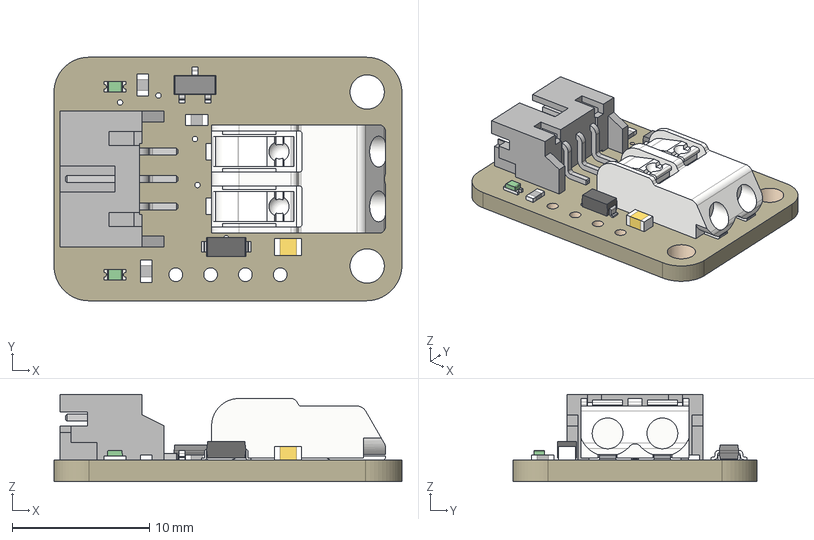
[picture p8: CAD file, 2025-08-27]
models/5648 MOSFET Driver.step
25.4 x 17.8 x 6.37 mm
Board
2.2uF+/35V+
RED x 2
10K x 3
JST PH 3
AO3406
2060-402/998-404
1N400x/SM4002

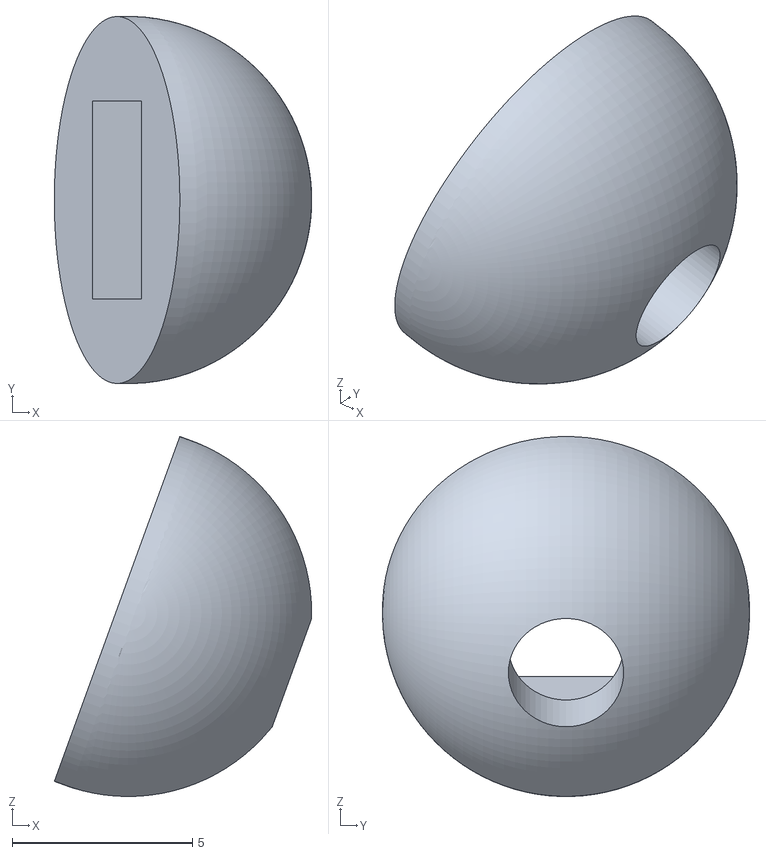
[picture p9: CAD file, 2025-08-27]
models/eyeball_B.stl
7.15 x 10.2 x 10.00

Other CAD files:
models/Gears v2.f3z
models/Pico LiPo 2 XL W v2.f3d
models/bottom_cover (1) v7.f3z

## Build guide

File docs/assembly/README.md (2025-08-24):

# Dalek Build Documentation

Central hub for building the animatronic RC Dalek. Follow steps in order (each step page has Previous / Next navigation plus a return link to this index).

## Assembly Steps (Mechanical / Lighting Phase)

1. [Step 1 – Gather / Print All Parts](./step1_parts.md) ✅
2. [Step 2 – Eyestalk Assembly](./step2_eyestalk.md) ✅
3. [Step 3 – Dome Assembly & LED Distribution Board](./step3_dome.md) ✅
4. [Step 4 – Neck Stack & Dome Integration](./step4_neck.md) ✅
5. [Step 5 – Arm & Shoulder Integration](./step5_shoulders_arms.md) ✅
6. [Step 6 – Skirt Assembly & Shoulder Attachment](./step6_skirt_assembly.md) ✅
7. [Step 7 – Fender Mechanism & Skirt Integration](./step7_fender_mechanism.md) ✅
8. [Step 8 – Wiring Harness Integration & Electronics Mounting](./step8_wiring_electronics.md) 🚧 (initial mounting only)
9. Step 9 – Firmware Flash & Configuration (📝 planned)
10. Step 10 – Gamepad Pairing & Control Mapping (📝 planned)
11. Step 11 – Audio Assets & Conversion (📝 planned)
12. Step 12 – Calibration, Tuning & Maintenance (📝 planned)

Later steps (8–12) expand into electronics, firmware, control, audio, and calibration once mechanical guide is finalized.

## Status Legend

✅ Complete | 🚧 In Progress | 📝 Planned / Placeholder

| Step | Status | Notes |
|---|---|---|
| 1 | ✅ | Comprehensive print & part BOM gathered |
| 2 | ✅ | Eyestalk LED subassembly with checkpoints |
| 3 | ✅ | Dome board with low‑side resistors & harness strategy |
| 4 | ✅ | Keyed neck stack & harness loop established |
| 5 | ✅ | Single clamp dual‑arm integration |
| 6 | ✅ | Skirt hemis + shoulder fastening |
| 7 | ✅ | Cam / pushrod / fender integration |
| 8 | 🚧 | Base: boards, speaker, motors, wheel gears & axle; Pico headers/SHIM; initial power, I2S & LED wiring |
| 9 | 📝 | Pico build + flash workflow |
| 10 | 📝 | Gamepad pairing & control mapping |
| 11 | 📝 | Audio asset conversion & deployment |
| 12 | 📝 | Calibration, tuning & troubleshooting matrix |

## Notes

- Legacy standalone dome subassembly file has been merged into Steps 2 & 3 (no separate `subassembly_dome.md`).
- Navigation blocks at the bottom of each step link forward/back and back to this index for faster browsing.
- Contributions welcome—open a PR to refine or extend planned steps.

---
Revision: 1.0 (2025‑08‑24) Updated index for completed Steps 1–7, added navigation policy, removed obsolete placeholders.

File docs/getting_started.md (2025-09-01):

# Getting Started Guide

## Project Overview

Welcome to the Exterminate Dalek project! This guide will help you get started with building and programming your own animatronic Dalek using a Raspberry Pi Pico W.

**What You're Building:**

- A Bluetooth-controlled animatronic Dalek
- Differential drive movement system
- Sound effects with I2S audio output  
- Responsive gamepad controls

## What You Need

### Essential Hardware

**Microcontroller:**

- 1x Raspberry Pi Pico W (RP2350 recommended)
- 1x USB-C cable for programming

**Motor System:**

- 1x Pimoroni Motor SHIM for Pico (DRV8833-based dual motor driver board). See: [Pimoroni Motor SHIM for Pico](https://shop.pimoroni.com/products/motor-shim-for-pico)
- 2x DC geared motors (6V, up to 1A each)
- Wheels and chassis materials

**Audio System:**

- 1x I2S DAC module (PCM5102A recommended)
- 1x Small speaker (4-8Ω, 3-5W)
- Audio amplifier (optional for louder output)

**Power Supply:**

- Battery pack (6-12V, 2A minimum)
- Voltage regulator for 5V rail
- Power switch and indicator LED

**Assembly Materials:**

- Breadboard or custom PCB
- Jumper wires and connectors
- Mounting hardware and chassis
- 3D printed or fabricated Dalek shell

### Development Tools

**Required Software:**

- Windows 10/11, macOS, or Linux
- Visual Studio Code
- Git version control

**Gamepad Support:**

- PlayStation 4/5 controller, or
- Xbox One/Series controller, or  
- Nintendo Switch Pro controller, or
- Generic Bluetooth gamepad

## Quick Start (30 Minutes)

### Step 1: Get the Code

**Clone the Repository:**

```bash
git clone https://github.com/your-username/Exterminate.git
cd Exterminate
git submodule update --init --recursive
```

**Open in VS Code:**

```bash
code .
```

### Step 2: Install Development Environment

**VS Code Extensions:**

When you open the project, VS Code will prompt to install recommended extensions:

- Raspberry Pi Pico (essential)
- C/C++ Extension Pack
- CMake Tools

Click "Install All" when prompted.

**Pico SDK Installation:**

The Raspberry Pi Pico extension will automatically download and configure the SDK. This may take a few minutes.

### Step 3: Build the Project

**Using VS Code:**

1. Open Command Palette (Ctrl+Shift+P)
2. Type "CMake: Configure" and press Enter
3. Select "Pico ARM GCC" when prompted
4. Type "CMake: Build" and press Enter

**Expected Output:**
```
[build] Building folder: Exterminate
[build] Build finished with exit code 0
```

### Step 4: Basic Hardware Setup

**Minimal Test Setup:**

For initial testing, you only need:

1. Raspberry Pi Pico W
2. USB cable connected to computer
3. Optional: LED on GPIO 25 (built-in LED)

**Test Flash:**

1. Hold BOOTSEL button on Pico W
2. Connect USB cable
3. In VS Code: Ctrl+Shift+P → "Raspberry Pi Pico: Flash"
4. Release BOOTSEL button

**Verify Success:**

- Pico W should reboot automatically
- Built-in LED should start blinking
- Check VS Code output for success message

## Hardware Assembly

### Power System

**Power Distribution:**

```
Battery (+) ──→ Power Switch ──→ Voltage Regulator ──→ 5V Rail
                    │
                    └──→ Motor Driver VIN (6-12V)

5V Rail ──→ Pico W VIN (Pin 39)
   └──→ I2S DAC VCC
```

**Important Notes:**

- Never exceed 12V input to motor driver
- Pico W can accept 1.8-5.5V on VIN pin
- Use common ground for all components

### Motor Connections

**Motor SHIM (DRV8833-based) Wiring:**

```
Pico W GPIO    Motor SHIM Pin    Function
------------   -----------    --------
GPIO 2      →  AIN1          Motor A Direction 1
GPIO 3      →  AIN2          Motor A Direction 2  
GPIO 4      →  BIN1          Motor B Direction 1
GPIO 5      →  BIN2          Motor B Direction 2
GND         →  GND           Ground
5V          →  VCC           Logic Power
Battery+    →  VIN           Motor Power
```

**Motor Wiring:**

```
Motor SHIM (DRV8833)        Left Motor     Right Motor
-------        ----------     -----------
AOUT1       →  Motor + (A)
AOUT2       →  Motor - (A)
BOUT1       →                 Motor + (B)
BOUT2       →                 Motor - (B)
```

### Audio System

**I2S DAC Connections:**

```
Pico W GPIO    PCM5102A Pin   Function
------------   ------------   --------
GPIO 18     →  BCK           Bit Clock
GPIO 19     →  DIN           Data Input
GPIO 20     →  LCK           Left/Right Clock
5V          →  VCC           Power
GND         →  GND           Ground
            →  OUT+/OUT-     To speaker/amplifier
```

**Speaker Connection:**

- Connect DAC output to speaker directly (low volume), or
- Connect through audio amplifier for higher volume
- Use 4-8Ω speaker rated for 3-5W

### Audio Setup

**Adding Sound Effects:**

1. Place MP3 files in `misc/` directory
2. Name them numerically: `00001.mp3`, `00002.mp3`, etc.
3. Run conversion script:

```powershell
# Windows PowerShell
.\tools\convert_audio.ps1

# Windows Command Prompt
tools\convert_audio.bat
```

This converts MP3 files to C header files for embedding.

**Rebuild After Audio Changes:**

After adding new audio files:

1. Run conversion script
2. Build project again (Ctrl+Shift+P → "CMake: Build")
3. Flash updated firmware

### Gamepad Pairing

**Pairing Process:**

1. Power on your Dalek (Pico W running firmware)
2. Put your gamepad in pairing mode:
   - **PS4/PS5:** Hold Share + PS button until light bar flashes
   - **Xbox:** Hold Xbox + Connect button until button flashes
   - **Switch Pro:** Hold Sync button until LEDs race
3. Wait for automatic connection (should take 10-30 seconds)
4. Test basic movement with analog sticks

**Troubleshooting Connection:**

- Ensure gamepad is charged
- Try different gamepad if available
- Check serial output for BluePad32 messages
- Restart Pico W if connection fails

## Basic Operation

### Control Mapping

**Movement Controls:**

- **Left Stick Y-Axis:** Forward/backward movement
- **Left Stick X-Axis:** Turning (differential steering)
- **Right Stick Y-Axis:** Eye stalk up/down

**Audio Controls:**

- **Face Buttons (A/B/X/Y):** Play different sound effects
- **D-Pad:** Additional sound effects
- **Shoulder Buttons:** Special audio commands

**Safety Controls:**

- **Start/Menu Button:** Emergency stop (disables motors)
- **Select/View Button:** Reset to normal operation

### Testing Each System

**Motor Test:**

1. Ensure motors are properly mounted and wheels attached
2. Use left analog stick to test movement
3. Verify both wheels turn in correct directions
4. Test emergency stop functionality

**Audio Test:**

1. Connect speaker to I2S DAC output
2. Press different gamepad buttons
3. Verify sound effects play correctly
4. Adjust volume if using amplifier

## Common Issues and Solutions

### Build Problems

**"CMake configuration failed":**

- Ensure Pico SDK is properly installed
- Try closing and reopening VS Code
- Check that all git submodules are initialized

**"Compilation errors":**

- Verify all required extensions are installed
- Check that you're using the correct compiler (Pico ARM GCC)
- Try cleaning and rebuilding (Ctrl+Shift+P → "CMake: Clean")

### Hardware Problems

**Motors not responding:**

1. Check all wiring connections
2. Verify power supply voltage (should be 6-12V)
3. Test motors directly with battery
4. Check DRV8833 power LED

**No audio output:**

1. Verify I2S wiring (especially clock signals)
2. Check speaker connections
3. Test with known-good audio source
4. Verify DAC power supply

**Gamepad won't connect:**

1. Try pairing process again
2. Ensure gamepad is in pairing mode
3. Check for other Bluetooth interference
4. Try different gamepad if available

### Software Issues

**Pico W won't flash:**

1. Hold BOOTSEL button while connecting USB
2. Verify Pico W appears as USB drive
3. Try different USB cable
4. Check for driver issues

**Erratic behavior:**

1. Check power supply stability
2. Verify ground connections
3. Look for loose wiring
4. Check serial output for error messages

## Next Steps

### Enhance Your Dalek

**Mechanical Improvements:**

- Design and 3D print custom Dalek shell
- Add LED effects for eyestalk and dome lights
- Implement head rotation mechanism
- Add sensor arrays (ultrasonic, camera)

**Software Features:**

- Add autonomous movement patterns
- Implement voice recognition
- Create preset movement sequences
- Add remote monitoring capabilities

**Advanced Audio:**

- Record custom Dalek voice samples
- Add real-time voice modulation
- Implement spatial audio effects
- Add background ambient sounds

### Learning Resources

**Documentation:**

- Read detailed module documentation in `docs/` folder
- Study source code for implementation details
- Review hardware schematics and pin assignments

**Community:**

- Join Raspberry Pi Pico community forums
- Share your build photos and videos
- Contribute improvements back to the project

**Further Projects:**

- Adapt code for other robot platforms
- Explore other Pico W capabilities
- Learn about embedded systems design
- Study robotics and control systems

## Safety and Best Practices

### Electrical Safety

- Always disconnect power when making wiring changes
- Use proper fuses and circuit protection
- Verify connections before applying power
- Keep workspace clean and organized

### Mechanical Safety

- Ensure all moving parts are properly secured
- Test emergency stop functionality regularly
- Use appropriate materials for structural components
- Consider weight distribution and stability

### Software Safety

- Test thoroughly before deploying
- Implement proper error handling
- Use version control for code changes
- Keep backups of working configurations

**Ready to Start Building?**

Follow this guide step by step, and you'll have a working Dalek in no time! Remember that robotics projects are iterative - start simple, test frequently, and add features gradually.

For detailed technical information, refer to the comprehensive documentation in the `docs/` folder.

**Exterminate... Responsibly!** 🤖

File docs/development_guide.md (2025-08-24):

# Development Guide

## Overview

This guide covers setting up the development environment, building the project, flashing firmware, and debugging the Exterminate Dalek system.

## Prerequisites

### Required Software

**Development Environment**:
- **Visual Studio Code** (recommended IDE)
- **Git** for version control
- **Python 3.6+** for audio conversion tools

**Pico SDK Toolchain**:
- **CMake** 3.13+ build system
- **Ninja** build tool  
- **ARM GCC Toolchain** for cross-compilation
- **Pico SDK** 2.0+ development libraries

### Hardware Requirements

**Development Board**:
- Raspberry Pi Pico W (RP2350 recommended)
- USB-C cable for programming and power
- Breadboard or development PCB

**Optional Debug Hardware**:
- SWD debugger (Raspberry Pi Debug Probe)
- Logic analyzer for signal debugging
- Oscilloscope for PWM verification

## Environment Setup

### VS Code Extension Installation

Install the following VS Code extensions:

```bash
# Core development extensions
code --install-extension ms-vscode.cpptools
code --install-extension ms-vscode.cmake-tools
code --install-extension raspberrypi.raspberry-pi-pico

# Additional helpful extensions
code --install-extension ms-python.python
code --install-extension ms-vscode.hexeditor
code --install-extension github.copilot
```

### Pico SDK Setup

**Automatic Setup (Recommended)**:
The Raspberry Pi Pico extension will automatically install the SDK when you open the project.

**Manual Setup**:
1. Download Pico SDK from GitHub
2. Set environment variable: `PICO_SDK_PATH=/path/to/pico-sdk`
3. Install toolchain following official Pico documentation

## Project Structure

```
Exterminate/
├── .vscode/                 # VS Code configuration
│   ├── c_cpp_properties.json
│   ├── launch.json
│   └── tasks.json
├── build/                   # Build output (generated)
├── docs/                    # Documentation
├── include/                 # Header files
│   ├── audio/              # Generated audio headers
│   ├── AudioController.h
│   ├── MotorController.h
│   └── exterminate_platform.h
├── lib/                     # External libraries
│   └── bluepad32/          # BluePad32 submodule
├── misc/                    # MP3 source files (not in git)
├── src/                     # Source code
│   ├── main.cpp
│   ├── AudioController.cpp
│   ├── MotorController.cpp
│   └── exterminate_platform.cpp
├── tools/                   # Build and development tools
│   ├── mp3_to_header.py
│   ├── convert_audio.ps1
│   └── convert_audio.bat
├── CMakeLists.txt           # Main build configuration
├── pico_sdk_import.cmake    # SDK import script
└── README.md               # Project overview
```

## Building the Project

### Quick Build (VS Code)

1. **Open Project**: Open the Exterminate folder in VS Code
2. **Select Kit**: Choose "Pico ARM GCC" when prompted
3. **Build**: Use Ctrl+Shift+P → "CMake: Build" or click Build button
4. **Flash**: Use Ctrl+Shift+P → "Raspberry Pi Pico: Flash"

### Command Line Build

```bash
# Configure build system
cmake -B build -G Ninja

# Build project
ninja -C build

# Or use CMake wrapper
cmake --build build
```

### Build Targets

Available build targets:

```bash
# Build main executable
ninja -C build Exterminate

# Build and create UF2 file for flashing
ninja -C build Exterminate.uf2

# Clean build
ninja -C build clean

# Rebuild everything
ninja -C build clean && ninja -C build
```

## Configuration Options

### CMake Build Options

Configure build with CMake options:

```bash
# Enable debug build
cmake -B build -DCMAKE_BUILD_TYPE=Debug

# Configure motor PWM frequency
cmake -B build -DMOTOR_PWM_FREQUENCY=20000

# Enable verbose build output
cmake -B build -DCMAKE_VERBOSE_MAKEFILE=ON

# Target specific Pico variant
cmake -B build -DPICO_BOARD=pico_w
```

### Audio System Configuration

**Converting Audio Files**:
1. Place MP3 files in `misc/` directory
2. Run conversion script:

```powershell
# Windows PowerShell
.\tools\convert_audio.ps1

# Windows Command Prompt  
tools\convert_audio.bat

# Manual Python execution
python tools\mp3_to_header.py misc include\audio
```

**Audio Build Integration**:
Audio headers are automatically included in the build. No additional configuration needed.

## Flashing Firmware

### UF2 Flashing (Recommended)

**Using VS Code**:
1. Hold BOOTSEL button while connecting Pico W
2. Use "Raspberry Pi Pico: Flash" command
3. VS Code will automatically build and flash

**Manual UF2 Flashing**:
1. Hold BOOTSEL button while connecting Pico W
2. Copy `build/Exterminate.uf2` to RPI-RP2 drive
3. Pico will automatically reboot and run firmware

### SWD Flashing (Advanced)

**With Raspberry Pi Debug Probe**:
```bash
# Flash via SWD (requires OpenOCD)
openocd -f interface/cmsis-dap.cfg -f target/rp2040.cfg \
  -c "program build/Exterminate.elf verify reset exit"
```

**SWD Wiring**:
```
Debug Probe    Pico W      Function
-----------    ------      --------
SWCLK     -->  SWCLK       SWD Clock
SWDIO     -->  SWDIO       SWD Data  
GND       -->  GND         Ground
VTREF     -->  3V3         Target Voltage Reference
```

## Debugging

### Serial Debug Output

**Enable Debug Output**:
Debug output is sent via USB serial (UART0):

```cpp
// In main.cpp
stdio_init_all();  // Enables USB serial

// Use standard printf for debug output
printf("Debug message: %d\n", value);
```

**View Debug Output**:
```bash
# Windows (PowerShell)
# Find COM port in Device Manager, then:
python -m serial.tools.miniterm COM3 115200

# Linux/macOS
python -m serial.tools.miniterm /dev/ttyACM0 115200

# Or use VS Code Serial Monitor extension
```

### VS Code Debugging

**Launch Configuration** (`.vscode/launch.json`):
```json
{
    "version": "0.2.0",
    "configurations": [
        {
            "name": "Pico Debug",
            "type": "cortex-debug",
            "request": "launch",
            "servertype": "openocd",
            "executable": "${workspaceFolder}/build/Exterminate.elf",
            "configFiles": [
                "interface/cmsis-dap.cfg",
                "target/rp2040.cfg"
            ]
        }
    ]
}
```

**Debug Features**:
- Breakpoints in C++ code
- Variable inspection
- Call stack examination
- Memory viewer
- Register inspection

### Common Debug Scenarios

**Motor Not Working**:
1. Check serial output for initialization messages
2. Verify PWM signals with oscilloscope/logic analyzer
3. Test motor controller in isolation
4. Check power supply stability

**Bluetooth Connection Issues**:
1. Monitor BluePad32 debug output
2. Verify controller pairing process
3. Check for interference
4. Test with known-good controller

**Audio Problems**:
1. Verify I2S signals with logic analyzer
2. Check audio file conversion process
3. Test with simple sine wave generation
4. Verify DAC connections and power

## Performance Profiling

### Built-in Profiling

Enable profiling in build configuration:

```cmake
# Enable profiling
set(ENABLE_PROFILING ON)
```

**Profiling Macros**:
```cpp
#include "profiling.h"

void critical_function() {
    PROFILE_START(critical_function);
    
    // Function implementation
    do_important_work();
    
    PROFILE_END(critical_function);
}
```

### Performance Monitoring

**Key Metrics to Monitor**:
- Motor control loop timing (<1ms)
- Audio buffer underruns
- Bluetooth event processing time
- Memory usage and fragmentation

**Monitoring Code**:
```cpp
// Monitor timing critical functions
uint32_t start_time = time_us_32();
motor_controller.update();
uint32_t execution_time = time_us_32() - start_time;

if (execution_time > 1000) {  // >1ms is concerning
    printf("WARN: Motor update took %lu us\n", execution_time);
}
```

## Testing

### Unit Testing Setup

**Test Framework**: Minimal custom framework for embedded testing

**Running Tests**:
```bash
# Build test target
cmake -B build -DBUILD_TESTING=ON
ninja -C build tests

# Run tests on host (cross-platform code only)
./build/tests/unit_tests
```

**Test Structure**:
```cpp
// Example test file
#include "test_framework.h"
#include "MotorController.h"

TEST(MotorController, SpeedClamping) {
    MockMotorHardware hardware;
    MotorController controller(test_config, &hardware);
    
    // Test speed clamping
    controller.setSpeed(1.5f);  // Over maximum
    ASSERT_EQ(hardware.getLastPWM(), 1.0f);
    
    controller.setSpeed(-1.5f); // Under minimum  
    ASSERT_EQ(hardware.getLastPWM(), -1.0f);
}
```

### Integration Testing

**Hardware-in-Loop Testing**:
1. Connect real hardware components
2. Run automated test sequences
3. Verify expected behavior
4. Log results for analysis

**Test Scenarios**:
- Gamepad input → motor response
- Emergency stop functionality
- Audio playback verification
- Power supply variations

## Troubleshooting

### Build Issues

**CMake Configuration Fails**:
1. Verify Pico SDK installation and path
2. Check CMake and Ninja versions
3. Clear build directory and reconfigure
4. Check for missing dependencies

**Compilation Errors**:
1. Verify all submodules are initialized
2. Check for missing include paths
3. Verify C++ standard compatibility
4. Check for conflicting library versions

**Linking Errors**:
1. Verify all source files are in CMakeLists.txt
2. Check for missing library dependencies
3. Verify symbol names and namespaces
4. Check for multiple definitions

### Runtime Issues

**DMA Channel Conflicts** (Fixed):
```
Runtime panic: "DMA channel X is already claimed"
```
**Root Cause**: Pico-extras I2S library expects to manage its own DMA channels internally.

**Solution**: Use resource discovery pattern in `AudioController::initialize()`:
```cpp
// DON'T: Pre-claim resources permanently
// int dma_channel = dma_claim_unused_channel(true);  // ❌ Causes conflicts

// DO: Discover available resources, then let library claim them
int dma_channel = dma_claim_unused_channel(false);   // ✅ Just find available
dma_channel_unclaim(dma_channel);                    // ✅ Release immediately
// Library claims internally during audio_i2s_setup()
```

**LED Staying Solid Instead of Breathing**:
- Symptom of DMA channel conflicts preventing proper system initialization
- Fixed by implementing resource discovery pattern above

**Gamepad Not Pairing**:
- Often caused by resource conflicts blocking BluePad32 initialization  
- Verify DMA channels are available for Bluetooth subsystem
- Check for "controller not pairing" messages in debug output

**System Won't Boot**:
1. Verify power supply and connections
2. Check for flash corruption
3. Try flashing bootloader
4. Use SWD debugger to check startup

**Unexpected Behavior**:
1. Enable verbose debug output
2. Use debugger to step through code
3. Check for race conditions
4. Verify hardware connections

**Memory Issues**:
1. Monitor stack usage
2. Check for memory leaks
3. Verify audio buffer sizes
4. Consider reducing feature set

## Contributing

### Code Style

**Formatting**: Use `.clang-format` configuration:
```bash
# Format all source files
clang-format -i src/*.cpp include/*.h
```

**Naming Conventions**:
- Classes: `PascalCase` (e.g., `MotorController`)
- Functions: `camelCase` (e.g., `setMotorSpeed`)
- Variables: `snake_case` (e.g., `motor_speed_`)
- Constants: `UPPER_CASE` (e.g., `MAX_SPEED`)

### Git Workflow

**Branch Strategy**:
```bash
# Create feature branch
git checkout -b feature/new-audio-system

# Make changes and commit
git add .
git commit -m "feat: Add new audio system with I2S support"

# Push and create pull request
git push origin feature/new-audio-system
```

**Commit Message Format**:
```
type(scope): description

[optional body]

[optional footer]
```

Types: `feat`, `fix`, `docs`, `style`, `refactor`, `test`, `chore`

This development guide provides everything needed to successfully build, debug, and extend the Exterminate Dalek project.

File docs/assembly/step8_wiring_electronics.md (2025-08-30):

# Step 8 – Wiring Harness Integration & Electronics Mounting

> Objective (Part 1): Secure the audio amplifier (MAX98357A breakout), MOSFET driver board, speaker, and both drive motors (with small drive gears) onto the `base_cover.stl`, establishing the physical foundation for later wiring, power distribution, and control electronics.
> Scope: ONLY the operations below. Later subsections (Part 2+) will handle main MCU, power, harness routing, strain relief, connectors, and cable dressing.
-> Prerequisites: Printed `base_cover.stl`, `drive_gear.stl` (2×), cleaned motor standoffs, verified hole sizes. Components on hand: MAX98357A (or compatible MAX audio board) with screw terminal block, MOSFET driver breakout (STEMMA JST PH style — e.g. Adafruit MOSFET Driver [Product 5648](https://www.adafruit.com/product/5648)), two N20 gear motors (verified ratio match), 28 mm speaker, required fasteners.

---
## 1. Parts & Hardware (This Sub‑Step)

| Category | Item | Qty | Notes |
|---|---|-----|---|
| Printed | base_cover.stl | 1 | Mounting platform (remix) |
| Printed | drive_gear.stl | 2 | Small motor pinion gears (press / slip fit) |
| Audio | MAX98357A I2S 3 W Class D Amp | 1 | With 3‑pin or 5‑pin screw terminal (L+, L− / Vin / GND / SD) |
| Driver | MOSFET Driver Board (STEMMA JST PH, e.g. Adafruit product 5648) | 1 | For higher current loads (lighting / actuators) |
| Audio | 28 mm 8 Ω 2 W speaker | 1 | Fits circular recess center of base_cover |
| Drivetrain | N20 gear motor (3 V, 1000 RPM) | 2 | Matched pair (identical ratio) |
| Fastener | M2.5 × 8 mm screw | 4 | Two per breakout (inserted from underside) |
| Fastener | M2.5 hex nut | 4 | Secures audio & MOSFET boards |
| Fastener | M1.7 × 4 mm screw | 4 | Two per motor (standoff mounting) |
| Wire | Speaker lead pair | 1 set | Sufficient length to reach amp terminals without tension |

Assumptions:

- Mount hole spacing on base_cover matches the footprints of the selected MAX board & MOSFET driver (common Pimoroni / Adafruit pattern). Adjust washers/spacers if board backs contact surface features.
- Drive gears are the smaller printed gears intended for direct motor shaft interface (not the larger wheel gears).

## 2. Tools

- #0 / #1 Phillips or appropriate driver for M1.7 and M2.5 heads (confirm head style)
- Needle nose pliers or small nut driver (for M2.5 hex nuts)
- Tweezers (nut positioning assistance)
- Flush cutters (trim any print stringing around holes)
- Small flat file / deburring tool (clear standoff tops if needed)

## 3. Preparation

1. Inspect `base_cover.stl` for print artifacts around board mounting holes and motor standoffs; remove stringing or blobs.
2. Test fit an M2.5 screw through each board mounting hole from BELOW the base cover to ensure clearance (clear with a hand twist drill if undersized—do not melt).
3. Test fit the M1.7 screws into the motor standoff pilot holes; they should bite with gentle torque (no pre‑tapping required). If overly tight, lightly ream; if loose, plan to add a micro drop of medium CA after final positioning (do not apply yet).
4. Verify both N20 motors spin freely (brief low‑voltage test) and match direction/ratio. Mark a small dot on one shaft flat for orientation reference.
5. Lightly chamfer the bore of each `drive_gear.stl` if a brim/elephant’s foot is present.

## 4. Audio Amplifier Board Mounting (Left Side)

Orientation Goal: Screw terminals face INWARD toward the center of the base so speaker wires route directly without crossing future harness paths.

1. Invert the base cover (underside up) on a soft surface to access mounting holes safely.
2. Insert two M2.5 × 8 mm screws UP through the left-side board mounting hole pair.
3. While holding screws in place with a fingertip, flip the base upright carefully without pushing screws back out.
4. Place the MAX98357A board over the protruding screw shanks in the planned orientation (terminals inward). Ensure no bottom-side components foul the surface; add a thin spacer if necessary (not usually required).
5. Thread on the two M2.5 hex nuts using tweezers to position, then tighten evenly. Stop at snug—do not bow the PCB.
6. Verify terminal block faces the speaker recess; clearance should allow a gentle wire loop from the speaker rim.

Checkpoint A (Amplifier): Board sits flat, terminals inward, nuts secure, no PCB flex.

## 5. MOSFET Driver Board Mounting (Right Side)

1. Repeat the underside insertion for two M2.5 × 8 mm screws on the right-side mounting hole pattern.
2. Flip upright and place the MOSFET driver breakout so its primary terminal / JST / header faces inward (toward central wiring zone) for short lead runs.
3. Secure with two M2.5 hex nuts; tighten alternating until just firm.
4. Confirm vertical alignment roughly matches the amplifier board (aesthetic & harness routing symmetry).

Checkpoint B (Driver): Board secure, inward-facing connectors unobstructed.

## 6. Speaker Placement & Connection

1. Dry place the 28 mm speaker into the circular recess—ensure it seats flush without rocking. If slightly proud, check for print burrs and remove carefully.
2. Route the pre‑tinned or stripped speaker lead pair to the MAX board’s speaker output terminals (often labeled L+ / L− or + / −). Maintain slack loop avoiding sharp bends over the speaker frame.
3. Loosen the two terminal screws, insert wire ends fully (no stray strands), and tighten firmly while supporting the board (avoid twisting the PCB).
4. Lightly tug each wire to confirm secure clamp.
5. Dress excess wire into a gentle S‑bend near the speaker edge—keep center area clear for future battery or harness components.

Checkpoint C (Speaker): Speaker sits flush, wires secure in terminals, no tension when gently lifting wires.

## 7. Motor Mounting & Drive Gear Installation

Orientation Change: For this build the motor shafts face OUTWARD toward the future wheel assemblies (wheel gears + axle not installed yet). The small `drive_gear.stl` parts (pinions) are installed now; the larger `wheel_gear.stl` and axle insertion will occur in a later sub‑step.

1. Identify LEFT and RIGHT motor standoff sets on the base cover (mirrored locations). Ensure mounting faces are clean and flat.
2. Orient the first N20 motor so its shaft points outward (away from the center cavity) toward the perimeter where the wheel gear will later reside.
3. Align motor mounting holes with the two standoff pilot holes.
4. Insert first M1.7 × 4 mm screw and turn 1–2 threads—do not fully tighten.
5. Insert second M1.7 screw; once both are started, alternate tightening until the motor is held snug (avoid over‑torque stripping the plastic thread). Motor should not rotate by hand once secured.
6. Repeat for the second motor on the opposite side with identical outward shaft orientation (shafts parallel and both pointing outward).
7. Press a `drive_gear.stl` (pinion) onto each outward-facing motor shaft: Align shaft flat with the gear’s internal flat (if modeled). Support motor body while pressing to avoid bending the shaft.
8. Seat each pinion fully but avoid excessive force—aim for minimal axial play while maintaining free rotation.
9. Spin each pinion gently; observe concentric rotation (no wobble). If resistance is high, remove, lightly relieve bore, and re‑install.

Deferred: Installation of `wheel_gear.stl` components and axle/spacer will follow in a later Part 2/3 sequence once additional chassis elements are in place.

Checkpoint D (Motors & Pinions): Both motors rigid, outward pinions fully seated, rotation smooth without binding.

## 8. Wheel Gear & Axle Installation

Goal: Install bearings into each `wheel_gear.stl`, insert the axle through the chassis supports, and mesh the large wheel gears with the previously installed motor pinions.

### 8.1 Parts (This Sub‑Step)

| Item | Qty | Notes |
|---|-----|---|
| wheel_gear.stl | 2 | Large driven gears (wheels) |
| 683ZZ bearing (3×7×3) | 4 | 2 per wheel (inner + outer) |
| 3 mm tube (axle / spacer) | 1 (≈60 mm) | As listed in BOM (ensure burr‑free ends) |

### 8.2 Preparation

1. Deburr axle ends lightly (fine file / Scotch‑Brite) so they chamfer and won’t shave bearing shields.
2. Test a single 683ZZ bearing in a wheel gear bore—target a light press fit. If excessively tight, warm gear slightly (hand‑warm only) or VERY lightly scrape bore. If loose, plan for a micro drop of removable retaining compound later (defer for now).
3. Confirm both wheel gear teeth are clean (remove stringing between teeth with a plastic dental pick—tooth profile must remain crisp).

### 8.3 Bearing Insertion

1. Press the FIRST bearing into one side of the wheel gear until fully seated (face flush with gear hub edge). Support the opposite side evenly; press straight (avoid tilt that can gouge bore).
2. Flip the gear and press the SECOND bearing into the opposite side. Bearings should meet or leave a minimal internal gap (<0.1 mm). No rattle when gently shaken.
3. Repeat for the second wheel gear.

Checkpoint E (Bearings): All four bearings seated flush, no rocking, smooth fingertip spin of inner race.

### 8.4 Axle & First Wheel Installation

1. Identify the left chassis support (choose a consistent reference; front of model aligns with eyestalk direction). You can start either side; stay consistent for documentation.
2. Begin inserting the 3 mm axle from OUTSIDE toward the center through the first chassis support hole—advance only enough so ~10–12 mm protrudes inside the cavity.
3. Slide the FIRST wheel gear (bearing pair installed) onto the protruding axle section with GEAR TEETH FACING INWARD (toward the centerline / motor pinions). Ensure full engagement of axle through both bearings.
4. Continue pushing the axle inward, guiding its leading end into the central opposite support bore. Do not yet push it fully through the far support.

### 8.5 Second Wheel Installation

1. As the axle emerges from the far side of the central support, stop with ~10–12 mm still outside.
2. Place the SECOND wheel gear onto the emerging axle end, again TEETH FACING INWARD toward the center.
3. Press the wheel assembly inward while simultaneously pushing the axle the remaining distance through the far (outer) support until both wheel gears sit between their respective outer and inner supports.
4. Center the axle so roughly equal protrusion (if any) exists on both outer faces. If design expects flush ends, adjust accordingly.

### 8.6 Mesh & Alignment Check

1. Verify each motor pinion meshes with its wheel gear: there should be slight backlash (a barely perceptible tick when holding gear & rocking pinion) but no visible gap causing partial tooth engagement.
2. Rotate each wheel gear by hand: Both should turn smoothly with even resistance; observe motor pinion rotation (motors will act as weak generators causing slight drag—normal).
3. Check axial play: Pull/push each wheel gear along axle. Total side‑to‑side movement should be minimal (<0.5 mm). If excessive, plan to add thin printed shims in a later refinement step (defer for now).
4. Inspect for rubbing: No contact between gear face and chassis support walls. If rubbing: verify bearings fully seated; lightly relieve interfering surface.

Checkpoint F (Wheel Assembly): Bearings flush, gears oriented teeth inward, smooth rotation, proper mesh backlash, minimal axial play.

NOTE: Do NOT apply lubrication yet. Lubricant (if desired) will be introduced after full drivetrain validation to avoid attracting debris during remaining assembly.

## 9. Pause Point / Deferred Work (End of Part 1)

If you intend to stop here, leave boards covered to prevent debris ingress. Otherwise continue directly into Part 2 (MCU header & Motor SHIM integration).

---

## Part 2 – Pico LiPo 2XL W Header & Motor SHIM Integration

Objective (Part 2 Segment A): Prepare the Pico LiPo 2XL W by soldering dual 10‑pin headers (one each side near the USB end) and mount/solder the Motor SHIM so it resides on the backside of the Pico with the QW/ST port aligned to the Pico’s USB connector edge. Final header pins will be clipped flush for clearance.

### 10. Parts (This Segment)

| Category | Item | Qty | Notes |
|---|---|-----|---|
| Control | Pico LiPo 2XL W | 1 | USB end reference faces forward/front of chassis |
| Control | 10‑pin male header strip | 2 | Standard 2.54 mm; will be trimmed flush post solder |
| Control | Motor SHIM for Pico | 1 | Sits on backside; QW/ST port alignment required |
| Spacer | Plastic separator (included with header) | 2 | Acts as solder height gauge (on backside) |
| Consumable | Flux pen | As needed | Improves wetting |
| Tool | Flush cutters | 1 | For pin trimming after soldering |

### 11. Tools (Additional)

- Fine tip soldering iron (temperature controlled)
- Leaded or unleaded solder (0.5–0.7 mm)
- PCB vise / helping hands (stability)
- ESD mat / wrist strap (recommended)
- Isopropyl alcohol + lint‑free swabs (flux cleanup)

### 12. Preparation

1. Inspect Pico pads (through‑hole) – ensure no oxidation; lightly apply flux.
2. Break or cut two 10‑pin header segments; verify pin count matches required pad span (USB end group on each side).
3. Decide which side is considered the “backside” (headers’ black plastic separators must end up on the backside so they can sit between Pico and Motor SHIM for consistent standoff). Orientation of the gold pin bevels is non‑critical because pins will be clipped.

### 13. Soldering Pico Headers

1. Place first 10‑pin header through the Pico from TOP (component side) so the black plastic separator is on the BACKSIDE (underside) of the board.
2. Tack one end pin: Heat pad + pin simultaneously; apply minimal solder forming a shiny fillet. Confirm header sits perpendicular. Reheat and adjust if tilted.
3. Tack the opposite end pin; verify alignment again.
4. Flow the remaining 8 joints: Keep tip clean; dwell just long enough for full wetting. Avoid excessive solder (bulbous joints may complicate later flush clipping).
5. Repeat for second header on the other side (same orientation).
6. Visual Inspection: All joints concave, shiny, no bridges between adjacent pads.
7. (Optional) Continuity sanity: Use multimeter in continuity mode to confirm each pin has continuity from top pad to protruding pin end and no shorts to neighbors.

Checkpoint G (Headers): Both 10‑pin headers soldered straight; plastic separators flush & even on backside.

### 14. Dry Fit Motor SHIM

1. Place the Motor SHIM onto the protruding header pins (backside of Pico). Ensure the QW/ST (STEMMA QT / Qwiic) port on the SHIM lines up horizontally with the USB connector edge – this ensures correct orientation.
2. Confirm the included plastic spacer (if separate) sits between the two boards uniformly; no bowing.
3. Check that no SHIM underside component fouls against any Pico component.

### 15. Solder Motor SHIM

1. With the assembly held in a vise (Pico on top, SHIM underside accessible), tack two diagonal pins (one corner of each header) to lock alignment.
2. Inspect alignment; adjust if needed by reheating a single tack joint.
3. Solder the remaining pins systematically, alternating sides to distribute heat.
4. Allow brief cooling intervals if board becomes noticeably warm.
5. Inspect all joints (good fillets, no icicles). Reflow any dull / grainy (“cold”) joints.

Checkpoint H (SHIM Mounting): SHIM fully seated, all header pins soldered, QW/ST port aligned with USB edge.

### 16. Pin Trimming & Cleanup

1. Using flush cutters, clip protruding pin ends on the SHIM side as close as practical to solder fillets without nicking joints.
2. Angle board slightly so cut fragments eject away from sensitive areas (wear eye protection).
3. Inspect for sharp edges or partial cuts; re‑clip if necessary.
4. Clean flux residues with IPA and swab; dry thoroughly.
5. Final continuity pass (spot check): Adjacent pins should not beep; random sample 3–4 pins for proper connection.

### 17. Interim Mounting Note

At this point the Pico + Motor SHIM assembly can be set aside ESD‑safe until chassis mounting holes & standoffs (if any) are detailed in the next segment. Do not yet connect power or peripherals.

### 18. Expansion Header Set (Battery Connector End)

Goal: Install the SECOND pair of 10‑pin headers at the battery connector end (opposite USB) to provide connection points for MOSFET driver outputs, LED anode lines, audio interface / enable, and future harness signals. These pins REMAIN UNCUT to function as a vertical interconnect field.

### 19. Additional Parts

| Category | Item | Qty | Notes |
|---|---|-----|---|
| Control | 10‑pin male header strip | 2 | Standard 2.54 mm – full length retained |

### 20. Orientation & Preparation

1. Identify the battery connector end of the Pico (opposite USB).
2. Ensure corresponding through‑holes are clear (wick old solder if needed).
3. Dry place a header: BLACK PLASTIC SPACER + LONG PINS must exit the BACKSIDE (Motor SHIM side). The short pin stubs will be soldered from the component/front side.
4. (Optional) Use a breadboard / printed jig to keep both headers orthogonal during soldering.

### 21. Soldering Expansion Headers

1. Support the assembly so the front/component side faces upward and the Motor SHIM is not bearing weight.
2. Insert first 10‑pin header from the front; confirm long pins protrude fully and spacer sits flush on backside.
3. Tack one corner pad; check 90° alignment. Reflow and adjust if tilted.
4. Tack opposite corner; re‑verify alignment.
5. Solder remaining eight pins with consistent dwell to avoid overheating earlier joints.
6. Repeat for second header on the opposite side.
7. Inspect: headers parallel to each other and to the earlier (USB‑end) clipped headers.
8. DO NOT CLIP these pins—full length required for harness connections & debugging clips.
9. Clean excess flux (avoid flexing long pins).

Checkpoint I (Expansion Headers): Two rear 10‑pin headers perpendicular, parallel, long pins unobstructed, no bridges.

### 22. Rationale & Future Use

- Long pins accept: MOSFET driver outputs, LED control lines (eye + dome), audio enable/data, additional sensors.
- Full length simplifies attaching logic analyzer or temporary jumper leads during bring‑up.
- Pin mapping / labeling will be provided in Part 3 once signal assignment is finalized.

### 23. ESD & Handling Note

Store assembly on anti‑static surface; added long pins increase leverage—avoid sideways knocks that could stress solder fillets.

---

## Part 3 – Initial Interconnect Wiring (Audio & Power Jumpers)

Objective (Part 3 Segment B): Fabricate and install the minimal point‑to‑point wiring needed to power the MAX98357A audio amplifier and bring it out of shutdown by tying SD high, while preparing clean, short Dupont jumper runs that avoid the cam / pushrod motion envelope.

Scope: ONLY the Pico ↔ MAX board short jumpers and creation of a 3‑way (tri‑fan) 3V3 distribution lead (Pico 3V3 → MAX VIN + MAX SD). Full harness (LED anodes, MOSFET driver signal, ground bus consolidation, battery / charge path, and labeling) deferred to Part 3 Segment C.

### 24. Important Power Note (Read First)

The Pico LiPo 2XL W 3V3 rail is regulator‑limited. The MAX98357A can accept 2.5–5.5 V and delivers far less output power at 3.3 V (acceptable for this build). DO NOT tie raw LiPo (VBAT ~3.7–4.2 V) directly to the 3V3 rail. If your “red JST wire” is raw battery, keep it isolated. Only proceed with the tri‑fan jumper if the third branch is intended for another 3V3 consumer (NOT raw VBAT). If unsure, omit the JST branch now—add later once confirmed with a multimeter (expect 3.3 V, not >3.5 V).

Assumption: In this step we connect ONLY Pico 3V3 → MAX VIN and Pico 3V3 → MAX SD (shutdown pin). The optional third branch to another 3V3 device is postponed unless voltage verified.

### 25. Parts (This Segment)

| Category | Item | Qty | Notes |
|---|---|-----|---|
| Wire | 26–30 AWG silicone hookup (red) | ~60–80 mm total | To fabricate tri‑fan 3V3 lead |
| Wire | 26–30 AWG silicone (black) | 2× short (15–25 mm) | Pico GND ↔ MAX GND (choose nearest pads) |
| Connector | Female Dupont single housings | 3–4 | For individual header pin terminations |
| Tubing | 2 mm heat‑shrink | 2–3 pieces | Insulate splices / bundle |
| Consumable | Flux, solder | As needed | Clean joints |
| Tool | Flush cutters, wire strippers | 1 each | Precision prep |

### 26. Wire Length Planning

1. Temporarily place the Pico+SHIM assembly where it will roughly mount relative to the base cover (estimate distance to MAX board). Keep wires inside an imaginary safe corridor CLEAR of pushrods/cams (visualize upward travel path).
2. Measure straight‑line distance Pico 3V3 header pin → MAX VIN pad; add 5–8 mm service loop. Typical length ≈ 25–35 mm.
3. Use same base length for branch to MAX SD (they are adjacent on MAX board). The third branch (if used later) should extend only enough to reach its destination without slack droop into moving mechanisms.

### 27. Tri‑Fan 3V3 Lead Fabrication

1. Cut one “trunk” wire equal to longest required branch + 8–10 mm (for splice).
2. Cut two branch wires (VIN, SD) to final length (allow 2–3 mm stripping).
3. Strip 2–3 mm insulation from one end of each branch and one end of the trunk. Pre‑tin lightly.
4. Form a small parallel bundle: place the two branch wire tinned ends side‑by‑side against the trunk’s tinned end (creating a 3‑way junction). Heat and flow just enough solder to merge—avoid a bulky blob.
5. Slide pre‑positioned heat‑shrink over the joint and shrink (do not trap stiff solder spikes—reflow if necessary for a smooth profile).
6. Strip & tin the free ends of all three wires.
7. (Optional) Add a 2–3 mm piece of heat‑shrink half on trunk/half on branch junction for strain relief.

Checkpoint J (Tri‑Fan): 3‑way splice compact, smooth, insulated; three free tinned ends sized for header insertion.

### 28. Installing 3V3 Lead

1. Push each tinned end into a female Dupont crimp contact (or pre‑crimped lead) and crimp/solder per quality preference; insert into single housings (individual, not 3‑in‑1) for flexible routing.
2. Connect trunk output to Pico 3V3 header pin (choose a clearly labeled 3V3 pin on the expansion header if available).
3. Connect branch leads to MAX VIN and MAX SD pins/headers (SD pulled high keeps amp enabled). If MAX board lacks pin headers yet, optionally solder directly—otherwise use short male header stubs.
4. Gently dress wires so they hug the board edges; no loop should descend below the motor pinion plane.

### 29. Ground Leads

1. Identify the closest Pico GND pin to the MAX board (minimize length).
2. Fabricate two short black GND jumpers (if separate returns desired) OR a single GND if board layout convenient.
3. Connect Pico GND → MAX GND (and a second GND for future shared return if reserved). Keep slack minimal.
4. Tug test each connector; re‑crimp if movement detected.

Checkpoint K (Power Wiring): 3V3 VIN & SD present, GND linked, no wire sag into drivetrain zone.

### 30. Clearance & Motion Check

1. Rotate cam mechanism manually (if fender assembly accessible) while observing wires; verify no incursion into moving sweep volume.
2. Invert assembly gently (simulate handling) to ensure wires do not fall into gear mesh.
3. If any loop droops, shorten or add a micro cable tie / miniature adhesive pad anchor (anchor details later Part 3C).

### 31. Preliminary Power Test (Optional Now / Mandatory Later)

1. WITHOUT speaker connected, apply USB power to Pico; verify no unexpected heat on MAX board (touch test carefully).
2. Measure voltage at MAX VIN vs GND (~3.3 V).
3. If stable, reconnect speaker and briefly play a low‑volume test tone (later firmware) or skip until firmware loaded.
4. If voltage deviates (>3.4 V or <3.2 V significantly under no load), investigate regulator output before proceeding.

### 32. Deferred Wiring (Do NOT Perform Yet)

- LED anode lines (Eye + Dome x2)
- Common LED ground return bundling / strain relief
- MOSFET driver signal (white) line assignment
- LiPo / charge path harness & power switch integration
- Audio data lines (BCLK, LRCLK, DIN) from Pico to MAX board
- Labeling & heat‑shrink color codes

### 33. Part 3 Segment C – MAX Audio Signal Wiring & LED Harness Integration

Objective: Complete logical connections between Pico and MAX board (I2S digital audio), prepare/terminate all four LED leads with Dupont females, dry‑fit the head (dome + neck + eyestalk) onto shoulders ensuring keyed rear alignment, route LED wires to avoid cam/pushrod interference, then lower full upper assembly onto the base and secure with four M3 screws.

Scope: Signal (not power) wiring for audio plus LED lead termination & connection. Final MOSFET driver input assignment still deferred.

#### 33.1 Additional Parts / Materials

| Category | Item | Qty | Notes |
|---|---|-----|---|
| Wire | 28–30 AWG (assorted colors) | 3 short | I2S lines BCLK, LRCLK, DIN |
| Connector | Female Dupont housings | 7–8 | 3× audio, 4× LEDs, spare |
| Wire | LED harness (existing) | 4 leads | Blue (Eye Anode), Red L, Red R, Black GND |
| Tool | Flush cutters / small snips | 1 | Trim lengths |
| Tool | Heat‑shrink (1.5–2 mm) | 4 pcs | LED lead strain relief (optional) |

Assumptions: MAX board pin labels (typical) – VIN, GND, DIN, BCLK, LRC (LRCLK / WSEL), SD (already tied high). Confirm silkscreen before soldering.

#### 33.2 Pico Pin Selection (Provisional)

Proposed mapping (adjust later in firmware if conflicts arise):

- BCLK  → Pico GP10
- LRCLK → Pico GP11
- DIN   → Pico GP12
- Eye LED anode (Blue)  → Pico GP13
- Dome Red Left anode   → Pico GP14
- Dome Red Right anode  → Pico GP15
- LED Common GND        → Any GND pin (use same rail already established)

Rationale: Consecutive GPIO block simplifies firmware pin muxing; leaves lower pins for motors / future sensors. Update table later if reserved pins collide with SHIM default mapping.

#### 33.3 Cut & Prepare Audio Jumpers

1. Dry route three short jumpers from chosen Pico pins (GP10–GP12) to MAX board pads (BCLK, LRCLK, DIN). Keep each wire just long enough with a tiny service loop (≈ 3–5 mm slack).
2. Strip 2–3 mm insulation, tin ends.
3. If MAX board already has header pins, terminate Pico ends with female Dupont; otherwise solder directly to MAX pads (preferred for lowest profile). If direct solder: feed wire from pad edge, wet pad then withdraw iron quickly.
4. Dress wires flat against board surfaces; avoid crossing over the speaker cavity.

Checkpoint L (Audio Signals): All three I2S lines connected, no solder bridges, wires clear of moving pathways.

#### 33.4 LED Lead Dupont Termination

1. Trim each of the four LED harness leads (Blue, Red L, Red R, Black) to the minimal length reaching selected Pico header pins with a 5–8 mm gentle loop.
2. Strip ~2 mm insulation; crimp female Dupont contacts (light solder wick assist if crimper quality marginal).
3. (Optional) Slide heat‑shrink over each lead base for strain relief; shrink after crimp solder touch‑up.
4. Label (tape flag or micro heat‑shrink color code) if color ambiguity exists.

#### 33.5 Head Assembly Dry Fit & Wire Routing

1. Place shoulder + arm + skirt + fender stack upright.
2. Align neck stack rear key with shoulder rear keyway (previous orientation conventions). Lower dome/neck assembly carefully—DO NOT yet glue.
3. Feed LED leads downward through the central cavity toward Pico expansion headers, keeping them centered—avoid hugging pushrod channels.
4. Gently articulate arms / rotate dome through allowable range ensuring no lead snags or wraps around the cam region.
5. Adjust loop sizes until wires remain tension‑free at extremes.

Checkpoint M (Head Routing): All four LED leads reach Pico area, no interference during motion tests.

#### 33.6 LED Connections to Pico

1. Connect Blue (Eye) → GP13 (as mapped) via expansion header.
2. Connect Red Left → GP14; Red Right → GP15.
3. Connect Black (LED common ground) to nearby GND pin (same ground bus as MAX board).
4. Quick continuity check: Verify no short between anode pins and ground (multimeter resistance mode; should show open / high until LEDs forward biased through resistors inside dome board).

Checkpoint N (LED Termination): All four leads seated, correct pins, ground secure, no shorts.

#### 33.7 Stack Onto Base Cover

1. Lift full upper assembly (fender + skirt + shoulders + neck + dome) above base_cover.
2. Ensure all intermediate wires (audio jumpers, tri‑fan 3V3, LED leads) are dressed inward and below future pinch lines.
3. Lower assembly straight down, visually tracking clearance at pushrods, gears, and speaker rim.
4. Align mounting holes; insert four M3 screws (from above) into base_cover mounting points—start each 2–3 turns.
5. Tighten incrementally in a cross pattern to snug (avoid warping base_cover). Do not overtighten into printed plastic.
6. Final motion test: Rotate dome, move arms, manually turn cam—confirm zero wire entanglement.

Checkpoint O (Chassis Integration): Assembly seated, 4× M3 engaged snug, all motions free, wiring clear.

#### 33.8 (Optional) Temporary Power-On Test

1. Apply USB power; verify Pico boots, MAX board not heating, no LED flicker on idle (unless firmware drives them).
2. If firmware available, briefly toggle each LED output (test script) verifying correct color/position.
3. Power down; disconnect until final harness strain relief added (later segment).

#### 33.9 Deferred / Next

- MOSFET driver signal pin assignment & wiring
- Full harness labeling & bundling strategy
- Battery integration (LiPo path, switch usage already on-board)
- Audio test tone playback validation
- Strain relief anchors & adhesive tie‑downs

---

---

## 10. Verification Checklist (Part 1 + Segment A)

| Item | Pass Criteria |
|---|---|
| Amplifier board | Mounted left, terminals inward, no flex |
| MOSFET driver | Mounted right, connectors inward |
| Speaker seating | Flush in recess, wires secure, slack present |
| Motor orientation | Shafts outward & parallel (wheel side) |
| Pinion seating | Both pinions fully pressed, no wobble |
| Wheel gear bearings | 2 per wheel fully seated, no rattle |
| Wheel gear orientation | Teeth inward toward pinions |
| Axle centering | Axle centered; minimal protrusion imbalance |
| Gear mesh | Even mesh, slight backlash, no binding |
| Motor fastening | 2 screws each, no spin or wobble |
| Drive gears | Fully seated, smooth manual rotation |
| Fastener integrity | No stripped plastic, nuts snug |
| Pico headers | Two straight 10‑pin headers installed |
| Header joints | Smooth, shiny, no bridges |
| Motor SHIM alignment | QW/ST port aligned to Pico USB edge |
| SHIM seating | Spacer flush; no board bow |
| Pins trimmed | All header pins clipped flush (no protruding spikes) |
| Expansion headers (rear) | Two 10‑pin sets installed at battery end |
| Expansion header orientation | Long pins & spacers on backside (Motor SHIM side) |
| Expansion pins condition | Not clipped; straight & parallel |
| Tri‑fan 3V3 splice | Compact, insulated, no exposed conductor |
| 3V3 distribution | Pico 3V3 → MAX VIN + SD (verified) |
| GND jumper | Secure, minimal slack, proper return |
| Wire clearance | No wires in cam/pushrod/gear envelope |
| Audio signals (Checkpoint L) | BCLK, LRCLK, DIN connected cleanly (no bridges) |
| LED routing (Checkpoint M) | Four LED leads reach Pico without interference |
| LED termination (Checkpoint N) | Anodes & ground on mapped pins, no shorts |
| Chassis integration (Checkpoint O) | Upper stack seated; 4× M3 secure; motion unobstructed |

## 11. Troubleshooting (Part 1 + Segment A)

| Symptom | Likely Cause | Remedy |
|---|---|---|
| Board tilts / rocks | Debris under PCB / uneven print | Remove, scrape high spot, remount |
| Speaker rattles | Not fully seated / warped recess | Deburr recess edge; add thin foam ring |
| Motor shifts under torque | Screws under‑tightened | Incrementally tighten both screws |
| Gear wobble | Ovalized bore / misaligned press | Reprint gear; press supporting shaft properly |
| Tight / no backlash | Axle not fully seated or gears forced inward | Re-seat wheels; ensure bearings fully home; verify pinion depth |
| Excessive backlash | Pinion not fully seated / axle off-center | Press pinion further; recenter axle; add shim later if needed |
| Axial wheel drift | Lack of lateral constraint | Plan thin shim (future step) or slight spacer print |
| Screw spins (no bite) | Over‑stripped plastic | Slightly larger screw, CA + re‑tap after cure |
| Expansion header lean | Uneven tacking / mechanical bump | Reheat one end, straighten, retack |
| Expansion header bridge | Excess solder / flux pooling | Flux + wick then reflow |
| Bent long pins | Handling stress | Realign gently with smooth pliers |
| Tri‑fan splice bulky | Excess solder / cold joint | Reflow with flux; wick excess; re‑shrink tubing |
| MAX not powering | Incorrect pin (not 3V3) / open splice | Verify pin mapping; continuity test splice; re‑solder |
| SD floating (amp off) | SD branch not connected or poor contact | Reseat Dupont; test continuity to splice |
| Wire fouls mechanism | Excess length / poor dressing | Shorten wire; add anchor; reroute tight to board edge |
| Header won’t sit flat | Solder blob in through‑hole / bent pin | Wick excess with braid; straighten pin; reseat |
| Bridged header pins | Excess solder / flux pooling | Use solder wick + flux; reflow clean joint |
| Dull / grainy joint | Insufficient heat or dirty tip | Clean tip, reflow with flux |
| SHIM misaligned | Tack shifted before full solder | Reflow one corner, reseat, retack opposite corner |
| Difficult pin trimming | Cutter not flush or joint too bulbous | Reflow to reduce solder volume, use sharp flush cutters |

## 12. Next Step

Proceed to Step 8 Part 3 – Mounting Pico + SHIM to Chassis & Power Distribution Planning (forthcoming).

---
Navigation: ← Previous [Step 7 – Fender Mechanism & Skirt Integration](./step7_fender_mechanism.md) | Next → (Pending Step 8 Part 2) | Index ↔ [Assembly Index](./README.md)

Revision: 0.1 (2025‑08‑24) Initial draft (Part 1) focusing on physical mounting only.
Revision: 0.2 (2025‑08‑24) Added Part 2 (Pico headers & Motor SHIM, expansion headers) and Part 3 Segment B (initial power wiring).
Revision: 0.3 (2025‑08‑24) Added Part 3 Segment C (I2S signal wiring, LED termination, head integration & chassis stack), standardized title.

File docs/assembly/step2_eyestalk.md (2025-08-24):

# Step 2 – Eyestalk Assembly

> Objective: Build and verify the eyestalk LED subassembly and prepare it for later integration with the dome and control electronics.
> Prerequisite: All printed eyestalk parts and small hardware gathered in Step 1.

> Geometry Clarification: The 3 mm tube (with the decorative `discs.stl` piece) remains fully exposed along its length. The printed `eye_stalk_A.stl` and `eye_stalk_B.stl` parts are only short mounting tabs/collars at the rear (opposite the eyeball) that secure the tube to the dome later. They do NOT form an enclosing sheath around the tube. At this stage the only enclosed element is the LED housed inside the eyeball shell.

## 1. Parts & Materials

| Category | Item | Qty | Notes |
|---|---|-----|---|
| Printed | eyeball_A.stl | 1 | Front half |
| Printed | eyeball_B.stl | 1 | Back half |
| Printed | eye_stalk_A.stl | 1 | Left stalk half |
| Printed | eye_stalk_B.stl | 1 | Right stalk half |
| Printed | discs.stl | 1 | Single printed cluster of aesthetic discs (slides onto tube) |
| Electronic | 3 mm blue LED | 1 | Forward voltage ~2.8–3.2 V |
| Electronic | 30 AWG silicone wire (blue) | 1 length | Eye LED anode (+) lead (tinned both ends) |
| Electronic | 30 AWG silicone wire (black) | 1 length | Ground / cathode lead (tinned both ends) |
| Proto | 2‑hole perf board snippet | 1 | Just two copper pads inline |
| Mechanical | 3 mm OD tube (SS or brass) | 1 (≈40 mm) | Shaft passes wires |
| Protective | Liquid electrical tape / conformal coat | As needed | Insulation |
| Optional | 1.5–2 mm heat shrink | 2 short pieces | Strain relief (alternative to perf) |

## 2. Tools

- Fine tip temperature‑controlled soldering iron
- Rosin core solder (0.5–0.7 mm)
- Flush cutters (sharp; for lead trimming)
- Tweezers or small needle nose pliers
- Magnification (head loupe) (recommended)
- Isopropyl alcohol + lint‑free swab (flux cleanup)
- Small brush / applicator for liquid electrical tape (if not built-in)

### Color Convention

For this build: all grounds / cathodes are BLACK. The eye LED anode uses a BLUE wire to visually match and simplify later identification when routing through the stalk and into the dome harness. (General +3V3 distribution elsewhere may still use red, but not for this specific subassembly.)

## 3. Pre‑Check

1. Dry‑fit the 3 mm tube in the stalk halves to confirm it seats fully and is not pinched.
2. Pass both wire lengths through the tube (without LED) to verify they slide freely. If tight, deburr tube ends and gently ream internal burrs with a fine needle.
3. Confirm LED polarity: longer lead = anode (+), flat side on rim = cathode (−).

## 4. LED Perf Subassembly

Follow this exactly; cramped tolerances later make rework tedious.

1. Prepare perf snippet: Cut / snap a fragment containing exactly two copper pads in a single row. De-burr edges so it sits flat.
2. Tin each copper pad lightly (just a sheen). Avoid creating a solder dome that would prevent the LED from seating flush.
3. Insert the 3 mm blue LED leads through the two perf holes from the non‑copper side so the LED body sits flush against the bare (non‑copper) face. Keep the LED centered and perpendicular.
4. Solder the LED leads on the copper side. Use minimal solder; you only need full wetting of pad + lead.
5. Trim both LED leads as close to the solder fillet as possible (nearly flush) using sharp flush cutters. Do not stress the solder joints—support the LED body while cutting.
6. Pre‑tin ~2–3 mm of one end of each 30 AWG wire (blue = anode, black = cathode). Keep the tin layer thin to ease insertion.
7. Insert the pre‑tinned wire ends into the SAME holes already occupied by the trimmed LED leads (you are essentially stacking into the remaining pad barrel). This can be fiddly:
   - Slightly angle the tinned end and rotate while applying gentle pressure.
   - If hole is fully filled, briefly reflow the solder with the iron while nudging wire in.
8. Once each wire end is partially seated, touch the soldering iron to reflow the existing joint; feed in a *very* small amount of solder only if necessary to achieve a smooth fillet.
9. Inspect joints (magnification): Both wires must be mechanically secure, no stray whiskers, and no solder bridges between pads.
10. Gently pull each wire (tug test). If movement occurs, reflow and add a trace more solder.

## 5. Insulation / Protection

1. Clean flux residue with a swab and isopropyl alcohol; dry thoroughly.
2. Apply a thin coat of liquid electrical tape or conformal coating over the exposed pad area and trimmed lead stubs. Ensure full coverage between the two pads and up the wire insulation transition.
3. Allow the coating to cure per manufacturer instructions (usually a few minutes tack, longer full cure). Avoid thick blobs that could increase diameter excessively.
4. Optional: Instead of coating, slip pre‑cut micro heat‑shrink over each joint before soldering (requires longer remaining LED leads) — not usually feasible with this minimal perf approach.

Rationale: The coated underside prevents accidental shorting against the interior of the metal tube or any conductive debris while keeping overall diameter minimal.

### Electrical Checkpoint 1 – Post LED / Perf / Insulation

Before enclosing anything inside the eyeball, do a quick live test:

1. Attach a current‑limited 3.3 V source (or bench supply set to 3.3 V, 20 mA limit) through a 150 Ω series resistor to the LED leads (BLUE = + via resistor, BLACK = −).
2. Verify steady illumination (no flicker when gently flexing wires). If intermittent, reflow joints now—much easier before mechanical integration.
3. Measure voltage across LED (expect ~2.8–3.2 V). Significantly lower may indicate a partial short; significantly higher means the resistor is not truly in series (re‑check test setup).
4. Disconnect power before proceeding.

## 6. Eyeball Assembly & Tube Integration

1. Seat the LED (with perf snippet) into the opening in `eyeball_A.stl` (front). It should be snug; lightly relieve the hole ONLY if the LED will not press in square. Do not force—avoid cracking the shell.
2. Test that the BLUE (anode) and BLACK (cathode) wires can pass cleanly through the rear opening in `eyeball_B.stl` without sharp bends. Enlarge the channel very slightly with a needle file if insulation scuffs.
3. Feed both wires through the hole in `eyeball_B.stl` then bring the two halves together, ensuring the LED remains centered and there is zero wire strain when the halves touch.
4. Hold the halves together and verify the seam alignment. Adjust LED depth if necessary so the lens sits correctly relative to the front surface.
5. Keeping the eyeball halves aligned, feed the free wire ends DOWN through the 3 mm tube until the tube reaches the rear opening of `eyeball_B.stl`.
6. Slide the single printed `discs.stl` piece (represents multiple stacked discs) onto the tube now. It is purely decorative (not a spacer) and must be installed before the tube is later CA‑bonded into the dome (cannot be added afterward).
7. Insert the tube fully into the rear eyeball hole; the perf board/LED should not twist. If the coating snags, withdraw slightly, re‑orient, and re‑insert with a gentle rotation.
8. Confirm: (a) LED centered, (b) halves fully closed, (c) no tension on wires, (d) tube seated flush or to designed depth, (e) discs positioned as desired.
9. Bond the eyeball halves: apply a minimal amount of thin CA glue around the interior seam (capillary method). Avoid flooding to prevent frosting. Optionally use activator sparingly *after* excess fumes dissipate.
10. Wick a tiny drop of CA where the tube meets the rear hole to lock it (avoid wicking CA onto wires). Let cure fully.
11. Electrical Checkpoint 2 – Post Tube Bond: Re‑test LED exactly as in Checkpoint 1. If the LED now fails or flickers, suspect CA migration, mechanical strain on a joint, or a short to the tube (inspect coating edge). Rework before continuing.
12. Do NOT yet glue the eyeball/stalk assembly into the dome; that occurs in the dome step.

Tip: To reduce CA fogging on the lens, keep airflow moving (small fan) and avoid enclosing the assembly while curing.

## 7. Stalk Mount Tabs Bonding

With the eyeball and tube already unified and discs installed, permanently bond the two small rear mounting tab pieces (they do not cover the tube length):

1. Test fit again: position `eye_stalk_A.stl` (left) and `eye_stalk_B.stl` (right) around the rear end of the tube only, confirming the tube’s seating feature engages and wires exit without pinch.
2. Lightly deburr any internal print artifacts that touch the discs or eyeball—remove ONLY what interferes.
3. (Optional) Lightly scuff (600–800 grit) the tube contact pads inside the halves for better CA adhesion; blow away dust.
4. Route the BLUE and BLACK wires straight out the rear channel; add a tiny piece of low‑tack tape to keep them centered if they spring sideways.
5. Apply small dots / short beads of medium (not thin) CA to: alignment posts, perimeter mating ribs, and the tube capture features inside the tab pieces. Avoid excess that could wick along the exposed tube toward the discs.
6. Close the halves starting from the eyeball end, ensuring seams align. Squeeze gently; do not torque. Wipe any squeeze‑out immediately with a clean swab (no accelerator yet).
7. Verify: (a) eyeball still centered, (b) decorative discs untouched and free to remain visually even, (c) tube fully seated front to back in the rear collar, (d) wires move freely when gently pulled.
8. Wick a *tiny* amount of thin CA at the rear tube exit if additional locking is desired—keep adhesive off wires.
9. Optionally apply accelerator sparingly from the *outside* after fumes have partially dissipated to reduce frosting risk.
10. Hold or tape in position until initial set; then let cure per adhesive spec before handling (~5–10 min typical for full handling strength).
11. Do NOT snap into the dome yet—dome integration occurs in the dedicated dome step to keep access for wiring. The exposed tube + discs should remain clean; avoid handling with adhesive on fingers.

## 8. Final Electrical Test (After Stalk Mount Tabs Bonded)

- Perform a final illumination check after Section 7 bonding to ensure no stress introduced a latent fault.
- Optional: gently rotate the eyeball while powered (without twisting wires) to be sure movement does not induce flicker.

## 9. Staging for Next Steps

- Coil and label the two wire leads (masking tape flag: "Eye + (Blue) / Eye − (Black)"). Recommended length to leave untrimmed: ≥150 mm until harness planning.
- Visually confirm no CA bloom on the lens; if present, very lightly polish later (do not attempt now while joints are green).

## 10. Troubleshooting Quick Reference

| Symptom | Likely Cause | Action |
|---|---|---|
| LED dead | Reversed polarity or cold joint | Reflow joints; verify anode to blue |
| LED intermittent | Hairline solder crack | Reflow & add minimal solder |
| Short to tube | Coating incomplete | Add second thin insulation layer |
| Wires won’t insert | Hole fully filled with solder | Reflow while gently pushing wire |
| High resistance dim LED | Excessively long thin wire / poor joint | Reflow; verify supply voltage |

## 11. Next Step

Proceed to Step 3 – Dome Assembly & LED Distribution Board.

---
Navigation: ← Previous [Step 1 – Gather / Print All Parts](./step1_parts.md) | Next → [Step 3 – Dome Assembly & LED Distribution Board](./step3_dome.md) | Index ↔ [Assembly Index](./README.md)

Revision: 0.2 (2025-08-24) Added revision line for consistency.

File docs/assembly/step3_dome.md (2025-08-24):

# Step 3 – Dome Assembly & LED Distribution Board

> Objective: Install the dome lighting (two red LEDs), integrate the completed eyestalk wiring, and prepare a small perf board power distribution node while preserving serviceability for later neck and body integration.
> Prerequisite: Step 2 eyestalk assembly fully completed and electrically verified (both Electrical Checkpoints passed, wires labeled, minimum 150 mm free lead length).

## 1. Parts & Materials

| Category | Item | Qty | Notes |
|---|---|-----|---|
| Printed | dome.stl | 1 | Shell (surface finish priority) |
| Printed | light_x2.stl | 2 | Transparent / translucent diffusers |
| Printed | dome_stalk_ver3.stl | 1 | Eyestalk pass‑through / support |
| Printed | stalk_tab.stl | 1 | Rotation / mechanical drive tab |
| Printed | dome_nut.stl | 1 | Internal retainer / lock |
| Printed | led_adapter_3mm_5mm.stl | 2 | 3mm-to-5mm LED centering adapter (Printables 995139) |
| Electronic | 3 mm red LED | 2 | Dome indicators (Vf ~2.0 V) |
| Electronic | 150 Ω resistor | 3 | One per LED (low‑side / cathode) |
| Proto | Perf board 31 × 16 mm | 1 | 2.54 mm grid (trimmed) |
| Wire | Red wire (down harness) | 2 lengths | Anode lines to main PCB (Left / Right dome LEDs) |
| Wire | Blue wire (down harness) | 1 length | Eyestalk anode line to main PCB |
| Wire | Black wire (down harness) | 1 length | Common ground return (post‑resistor bus) |
| Wire | Red wire (short pigtails) | 2 short | LED anode pigtails from each red LED to board |
| Wire | Black wire (short pigtails) | 2 short | LED cathode pigtails (into individual resistors) |
| Wire | Blue wire (from Step 2) | 1 | Eyestalk anode lead (trim to board) |
| Wire | Black wire (from Step 2) | 1 | Eyestalk cathode lead (into its resistor) |
| Fastener | M2 × 6 mm screw | 2 | Board / internal hardware securing (if used) |
| Adhesive | Tiny CA / hot glue / UV resin | As needed | Board & diffuser retention |

Note: All three LEDs use low‑side (cathode) resistors located on this subboard. This permits individual anode control (blinking / modulation) from the main PCB with just four wires exiting the dome (3 anodes + 1 common ground).

## 2. Tools

- Soldering iron (fine tip)
- Rosin core solder (0.5–0.7 mm)
- Flux pen (optional but recommended)
- Flush cutters (leads + perf trim)
- Fine file / 400–600 grit sandpaper (edge deburr)
- Tweezers / small pliers
- Multimeter (continuity + voltage)
- Bench / current‑limited 3.3 V supply (or Pico + series resistors)
- Masking tape (wire labeling & temporary retention)

### Color Convention Recap

- BLUE: Eyestalk LED anode (+) (separate control line).
- RED (two lines): Left & Right dome LED anodes (+) (independent control possible).
- BLACK: Common ground return (after individual resistors).

## 3. Perf Board Design

Topology (Low‑Side Current Limiting):

- Each LED cathode connects via its own 150 Ω resistor to a common ground bus.
- All three resistor ground ends join to the single black ground down‑wire.
- Each LED anode remains isolated and leaves the dome on its own control wire (two red, one blue) for direct drive (active‑high) from the main PCB pins (or via transistors later if needed).

Layout Goals:

- Group three resistors in a row forming a neat barrier between LED cathode pigtails and ground bus.
- Provide clearly labeled through pads (or adjacent paired pads) for: A_RED_L, A_RED_R, A_EYE (blue), and GND.
- Maintain mechanical clearance so adapters / diffusers seat without pressing on solder joints.
- Keep at least one outer hole row free for anchoring glue / resin.

Wire Strategy:

- Short local pigtails (red = anode, black = cathode) run from each dome LED up at the diffuser position back to the perf board.
- Eyestalk wires (blue anode, black cathode) are fed through the rectangular opening (future stalk snap area) BEFORE snapping stalk in, trimmed, and soldered to board pads (blue to A_EYE pad, black to its resistor input pad).
- Four-wire down harness (2× red anodes, 1× blue anode, 1× black ground) exits through `dome_stalk_ver3` central channel.

Electrical Behavior:

- Driving a red LED: Set its anode line HIGH (3.3 V); current flows anode → LED → resistor → ground bus → common ground lead.
- Eye LED behaves identically on blue anode line.
- Typical current per LED ≈ (3.3 V − Vf_LED) / 150 Ω → red: (3.3 − 2.0)/150 ≈ 8.7 mA; blue eye (assuming Vf ≈ 2.9 V) ≈ 2.7 mA (slightly dim). Use 120 Ω for eye if higher brightness desired (optional note on board).

Expected Total Current (all on): ~20–24 mA depending on chosen eye resistor value.

## 4. Assembly Steps

1. Cut perf board to 31 × 16 mm; deburr edges (no copper burrs to nick insulation).
2. Plan pad usage: reserve one edge row for common ground bus; mark three adjacent isolated pads (or pad pairs) for anodes A_RED_L, A_RED_R, A_EYE.
3. Pre‑tin pads for the three resistors and the ground bus.
4. Prepare the two red LEDs: solder a short red pigtail to each anode and a short black pigtail to each cathode (long lead = anode). Keep pigtails just long enough to comfortably reach board (avoid excess bulk). Optional heat shrink on individual joints.
5. Insert each LED into its `led_adapter_3mm_5mm.stl`, then slide that adapter/LED subassembly into a `light_x2.stl` diffuser. Confirm snug but not forced.
6. Press‑fit each populated diffuser (light) into its hole on the dome top from the outside. Lenses/adapters should sit flush. If resistance is high, lightly relieve the dome hole—not the diffuser—until smooth press fit.
7. (Optional) Apply a tiny fillet of thin CA from the INSIDE perimeter of each hole to lock the light in place. Avoid wicking onto lenses.
8. Position the perf board loosely inside the dome; route the four LED pigtail pairs (2× red/black) to their intended pads without crossing sharply.
9. Solder each black cathode pigtail to one end of its own 150 Ω resistor; solder the opposite end of each resistor to the forming ground bus (do NOT connect the ground down‑wire yet).
10. Solder each red anode pigtail to its labeled anode pad (A_RED_L / A_RED_R). Keep pads isolated (no solder bridges).
11. Feed the eyestalk wires (blue anode, black cathode) ONLY through the rectangular opening where the stalk will later snap (do not snap stalk yet). Trim to length while leaving ~10–15 mm service slack to the board.
12. Solder eyestalk black (cathode) to the third resistor input; solder that resistor’s output to the ground bus.
13. Solder eyestalk blue (anode) to pad A_EYE.
14. Install the four down‑harness wires: two RED (from A_RED_L and A_RED_R pads), one BLUE (from A_EYE pad), and one BLACK from the common ground bus. Provide strain relief (small adhesive dab or short heat‑shrink over pad + insulation).
15. Electrical Checkpoint 1 (Board + All LEDs): Apply 3.3 V individually (one at a time) to each anode down‑wire while grounding the black common. Verify correct brightness; no other LEDs should glow faintly. Log current per LED.
16. After successful test, SNAP the eyestalk assembly into the rectangular opening. This can require firm, even pressure and slight rocking. Support the dome to avoid flex cracks. Ensure existing wires are not pinched and have relief.
17. Orient `dome_stalk_ver3.stl` under the dome so that the curved slit for the neck pin is to the LEFT of the eyestalk when looking down along the eyestalk facing forward. Route the four-wire harness down the center channel.
18. Secure `dome_stalk_ver3.stl` with two M2 × 6 mm screws. Tighten only until snug—do NOT over‑torque (threads are in printed plastic and can strip). If resistance spikes, back out and clear debris.
19. Electrical Checkpoint 2 (Post Snap & Stalk Install): Repeat quick per‑anode test; gently flex stalk and harness. No flicker permitted.
20. Electrical Checkpoint 3 (Final Dome Subassembly): Power all three anodes together briefly; verify combined current in expected range. Observe for thermal issues (none expected at <30 mA total).

Tip: Keep adhesive away from LED lens edges to prevent diffusion artifacts.

## 5. Wiring Reference

| Wire | Origin | Destination (Later) | Notes |
|---|---|---|---|
| Red Anode L | A_RED_L pad | MCU pin / driver | Left dome LED control (active HIGH) |
| Red Anode R | A_RED_R pad | MCU pin / driver | Right dome LED control (active HIGH) |
| Blue Anode Eye | A_EYE pad | MCU pin / driver | Eyestalk LED control (active HIGH) |
| Black GND | Ground bus (post 3 resistors) | Main PCB ground | Common cathode return |

## 6. Verification Checklist

| Item | Pass Criteria |
|---|---|
| Red LEDs polarity | Each illuminates alone when its anode is driven HIGH (others off) |
| Individual resistors | Three total: one per LED on cathode side |
| Eye LED resistor | Present on board (no external series R required) |
| Isolation | No ghosting when only one anode energized |
| Current draw | Per LED within spec (≈8–9 mA red, expected eye value) |
| Mechanical clearance | Board secure; adapters & diffusers not stressing leads |
| Light retention | Lights firmly seated; optional CA fillet applied internally only |
| Eyestalk snap fit | Fully seated; no wire pinch; orientation correct |
| Stalk orientation | Curved slit on `dome_stalk_ver3` is left of eyestalk (forward view) |
| Wire freedom | Movement causes zero flicker |
| Diffuser seating | Uniform glow; no major edge leaks |

## 7. Troubleshooting

| Symptom | Likely Cause | Action |
|---|---|---|
| One red LED dark | Reversed polarity or cold joint | Reflow / correct orientation |
| All LEDs dark | Missing ground or test powering method | Verify ground continuity & correct anode test point |
| One red LED dark | Open anode wire or cold solder at resistor | Reflow / continuity test anode path |
| Eye LED dark | Open anode or cathode resistor joint / stalk pinch | Reflow joint; check wire not crushed under snap |
| Light assembly loose | Insufficient press fit / no internal CA | Add tiny internal CA fillet (avoid lens) |
| Stalk misaligned | Incorrect stalk base orientation | Remove stalk base, rotate so slit is left of eyestalk, re‑secure |
| Excess current draw | Resistor shorted or wrong value | Measure resistor; replace |
| Ghosting (faint glow) | Leakage path / flux residue | Clean board; ensure anodes isolated |
| Flicker on movement | Strain on solder joint / insufficient relief | Add strain relief / reflow cracked joint |
| Uneven brightness | Mismatched resistor values | Measure resistors; replace incorrect |

## 8. Staging for Next Step

- Do NOT install `stalk_tab.stl` or `dome_nut.stl` yet; these will be fitted during Neck Assembly (Step 4) to preserve access and alignment flexibility.
- Coil and temporarily secure harness with low‑tack tape inside dome cavity leaving ~80–100 mm protruding for neck routing.
- Document (photo) the board layout for future reference / troubleshooting before closing up.
- Confirm all labels legible.

## 9. Next Step

Proceed to Step 4 – Neck Stack & Dome Integration.

---
Navigation: ← Previous [Step 2 – Eyestalk Assembly](./step2_eyestalk.md) | Next → [Step 4 – Neck Stack & Dome Integration](./step4_neck.md) | Index ↔ [Assembly Index](./README.md)

Revision: 0.1 (2025‑08‑23) Initial draft integrated with Step system.

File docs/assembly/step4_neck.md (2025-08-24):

# Step 4 – Neck Stack & Dome Integration

> Objective: Stack and align the neck ring assembly, route the 4‑wire dome harness cleanly, and finalize the mechanical interface between the dome (Step 3) and the body via neck pin & stalk hardware.
> Prerequisites: Completed Step 2 (Eyestalk) & Step 3 (Dome Subassembly) with labeled harness (ANODE RED L, ANODE RED R, ANODE EYE BLUE, GND BLACK). `stalk_tab.stl` and `dome_nut.stl` not yet installed.

## 1. Parts & Materials

| Category | Item | Qty | Notes |
|---|---|-----|---|
| Printed | neck_a.stl | 1 | Base segment (PLA+/black) |
| Printed | neck_b.stl | 1 | Diffuser ring (transparent PETG) |
| Printed | neck_c.stl | 1 | Spacer (PLA+/black) |
| Printed | neck_d.stl | 1 | Diffuser ring (transparent PETG) |
| Printed | neck_e.stl | 1 | Spacer (PLA+/black) |
| Printed | neck_f.stl | 1 | Top ring (transparent PETG) |
| Printed | neck_pin.stl | 1 | Rotation limit pin |
| Printed | stalk_tab.stl | 1 | Deferred from Step 3 |
| Printed | dome_nut.stl | 1 | Internal stalk retainer |

## 2. Tools

- Needle file / deburring tool
- Flush cutters (trim stray stringing inside channels)
- Fine tweezers / hemostats (wire guiding)
- Multimeter (continuity sanity check)

*No adhesives or lubricants required for this step.*

### Harness Recap

Four conductor bundle from dome:

- Red (Left Dome Anode)
- Red (Right Dome Anode)
- Blue (Eye Anode)
- Black (Common Ground)
Bundle should remain untwisted; provide gentle spiral if rotation is planned (avoid tight twist that adds spring force).

## 3. Neck Stack Planning

Order (bottom → top): neck_a (with center shaft + rear key) → neck_b → neck_c → neck_d → neck_e → neck_f → (dome interface).

Design Considerations:

- Pure friction stack: no glue; components remain serviceable.
- Rear KEY: neck_a's center shaft has a longitudinal key along the REAR (opposite eyestalk). Each subsequent ring has a matching internal notch so orientation is automatic—do not force if misaligned; back off, realign keyway, slide again.
- Maintain a clear central bore; harness must move freely.
- Neck pin provides rotation stop; it must align with the curved slot in the dome stalk.

Optional Dry Run:

1. Slide all rings and pass a scrap wire through to confirm bore continuity.
2. Identify any internal zits / elephant’s foot; lightly scrape or sand.

## 4. Preparation

1. Inspect each ring’s inner channel; remove stringing.
2. Lightly chamfer (optional) the leading inner edge of each bore with a deburring tool to reduce abrasion on wires.
3. (Optional) Test a thin PTFE / nylon washer between neck_f and dome underside if you anticipate frequent rotation.
4. Group the three anode wires together temporarily with a small piece of low‑tack tape 20–30 mm below dome exit; leave ground slightly offset for easy identification.

## 5. Harness Routing Strategy

- Stack the entire neck (A→F) FIRST over the fixed center shaft that is part of neck_a; bore stays empty initially.
- Lower the dome so the dome stalk slides INSIDE neck_a's center shaft and neck_pin enters slot—this captures the stack.
- Form a relaxed service loop just beneath the stalk base (above neck_f) by pulling a little slack back upward; this loop absorbs rotation.
- Keep harness centered; if it drifts to a wall, gently wiggle while pulling—do not twist hard.

## 6. Assembly Steps

1. Place neck_a on a flat, level surface (top facing up).
2. Slide neck_b down until the rear key seats in its notch (orientation enforced). No rocking.
3. Slide neck_c (keyed); correct any tilt immediately.
4. Slide neck_d, then neck_e (keyed automatically, no marking required).
5. Slide neck_f (keyed). Verify vertical alignment: no radial steps; top surface concentric with neck_a. Empty bore smooth end‑to‑end.
6. Insert neck_pin into LEFT side hole of neck_f (front = eyestalk side, rear = keyed side) until fully seated; hand ream only if required.
7. Lower the dome/eyestalk assembly straight down so the neck_pin enters the curved slot on the LEFT of the dome stalk AND the dome stalk slides concentrically inside neck_a's keyed center shaft (rear key still opposite eyestalk).
8. Install `stalk_tab.stl` on the exposed threaded end/post with its downward tab pointing toward the eyestalk (forward reference).
9. Thread on `dome_nut.stl` until just snug (dome still rotates). Do NOT over‑tighten; slight looseness ensures free motion and keeps shaft round.
10. Feed the harness: From dome underside, guide the four wires down through the hollow dome stalk and neck_a shaft. If friction occurs, use tweezers from below to pull each wire sequentially; avoid twisting bundle.
11. Create a small service loop: pull 15–20 mm of harness back upward beneath the stalk base, then relax to form a gentle arc.
12. Rotation Test: Push tab left/right; dome should sweep until slot edges meet neck_pin without the harness tightening. Resize loop if needed.
13. Wire Dressing: Ensure harness exits centered below neck_a; straighten any unintended twist; retag labels if obscured.
14. Electrical Checkpoint: Individually energize each anode (current‑limited) while rotating—verify no flicker or ground interruption.

## 7. Verification Checklist

| Item | Pass Criteria |
|---|---|
| Bore clearance | Harness feeds smoothly after full stack; no scraping |
| Rotational stop | neck_pin engages slot smoothly both directions |
| Harness slack | Loop present; no tension at extremes |
| Eyestalk orientation | Forward; stalk tab aligned downward toward eyestalk |
| Ring alignment | Vertical; no radial step between rings |
| Dome retention | Nut snug; dome rotates with gentle tab push |
| Electrical continuity | All 3 anodes + ground intact through movement |

## 8. Troubleshooting

| Symptom | Likely Cause | Action |
|---|---|---|
| Dome binds / high friction | Over‑tightened dome nut / misaligned rings | Loosen nut slightly; realign stack |
| Limited rotation | Neck_pin not fully seated in slot | Reseat dome ensuring pin in curved slot |
| Early wire tension | Service loop too small or skipped | Recreate loop (Step 9) and retest |
| Flicker on rotation | Harness pinched under a ring | Lift top rings sequentially; free harness |
| Pin won’t seat | Hole undersized | Hand ream lightly; avoid enlarging slot engagement angle |

## 9. Staging for Next Step

- Coil remaining harness length gently inside body cavity zone or secure to temporary anchor to avoid accidental tug.
- Photograph inside bore showing slack loop for future documentation.
- Prepare for Step 5 (Shoulders & Appendages) which will introduce arm/gun assemblies and additional wiring paths.

## 10. Next Step

Proceed to Step 5 – Arm & Shoulder Integration.

---
Navigation: ← Previous [Step 3 – Dome Assembly & LED Distribution Board](./step3_dome.md) | Next → [Step 5 – Arm & Shoulder Integration](./step5_shoulders_arms.md) | Index ↔ [Assembly Index](./README.md)

Revision: 0.1 (2025‑08‑23) Initial draft of neck stacking & integration.

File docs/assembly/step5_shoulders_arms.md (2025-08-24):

# Step 5 – Arm & Shoulder Integration

> Objective: Build both arm subassemblies (plunger & gun), establish precise tube overhangs with spherical joints, then install them into the single shoulder part (`shoulders.stl`) retaining motion with clamps and M3 screws without over‑tightening.
> Prerequisites: Step 4 complete (neck & dome integrated). Printed parts on hand: `shoulders.stl`, 4× `ball_x4.stl`, `plunger.stl`, `gun_tubes.stl`, 2× `ball_clamp.stl`. Tubes pre‑cut to 75 mm (plunger) and 57 mm (gun).

## 1. Parts & Materials

| Category | Item | Qty | Notes |
|---|---|-----|---|
| Printed | shoulders.stl | 1 | Dual‑socket shoulder body (left/right integrated) |
| Printed | ball_x4.stl | 4 | Four identical halves → 2 spheres |
| Printed | ball_clamp.stl | 1 | Single dual-arm retainer (embossed text faces OUT) |
| Printed | plunger.stl | 1 | LEFT arm end effector |
| Printed | gun_tubes.stl | 1 | RIGHT arm end effector |
| Raw | Tube 75 mm | 1 | LEFT arm shaft |
| Raw | Tube 57 mm | 1 | RIGHT arm shaft |
| Consumable | CA glue (thin/medium) | Minimal | Tiny dots only |
| Optional | CA accelerator | As needed | After alignment verified |
| Optional | Fine sandpaper (400+) | Strip | Deburr tube ends |
| Hardware | M3 screw (≈10–12 mm) | 1 | Single central screw for shared clamp |
| Optional | M3 washer | 1 | If seat supports; prevents screw head sink |

Assumption: Tubes already cut square; deburr inner & outer edges lightly.

## 2. Tools

- Flush cutters / deburring tool (print nubs, tube edge cleanup)
- Digital calipers or steel ruler (verify overhangs)
- Fine tip marker (temporary length marks)
- Tweezers / small clamp (hold halves during cure)
- #1/#2 Phillips or hex driver (per M3 screw head)
- Flashlight (inspect clamp seating)

## 3. Design & Alignment Notes

- Single Shoulder Body: `shoulders.stl` provides LEFT (plunger) and RIGHT (gun) sockets; no separate left/right housings.
- Spheres: Each full sphere = two `ball_x4` halves. Interior should be light slip fit. If tight: light scrape; if loose: rely on minimal CA spot tacking.
- Overhang Measurements: 75 mm tube → 19 mm (short) / 46 mm (long). 57 mm tube → 17 mm (short) / 30 mm (long). Measurements are from OUTER sphere surface to tube ends post‑assembly.
- Functional Ends: Long overhang always receives plunger or gun_tubes.
- Adhesive Strategy: 2–3 tiny (≈1 mm) dots near perimeter; avoid flooding to keep potential adjustability until locked.
- Clamp Orientation: Embossed text (e.g., "OUT") must remain readable when looking into the shoulder interior after installation; ensures correct chamfer orientation contacting BOTH sphere bands.
- Retention vs Locking: Single screw should only secure, not compress; both arms must articulate smoothly with moderate hand force. Tightening affects BOTH joints—adjust incrementally.
- Plastic Thread Care: First drive forms threads—advance slowly, back off to clear chips if resistance spikes.

## 4. Preparation

1. Inspect & Deburr: Clean `ball_x4` halves (remove elephant’s foot, stringing) and both tube ends (inner & outer chamfer light).
2. Dry Fit Halves: Ensure each half slides on its tube without force; correct with light scrape if required.
3. Mark Overhangs:
   - 75 mm tube: From one end mark 19 mm; from the opposite end mark 46 mm.
   - 57 mm tube: Mark 17 mm and 30 mm from opposite ends.
4. Shoulder Socket Prep: Inspect both sockets of `shoulders.stl`; remove any blobs that could high‑spot the sphere. Optional: ultra‑thin PTFE trace.
5. Stage Clamp & Screw: Confirm the single M3 screw threads freely through clamp hole (clear print fuzz now, not over the joints).

## 5. LEFT Arm Sphere & Plunger (75 mm Tube)

Target overhangs after sphere placement: 19 mm (short) and 46 mm (long).

1. Select two ball halves for this sphere; identify any visually cleaner seam edges for outward facing sides.
2. Slide first half onto tube roughly to center; do NOT set depth yet.
3. Add tiny CA dots to mating rim of the second half (avoid interior bore); align and press halves together around tube.
4. Immediately slide the forming sphere along tube until overhangs match 19 mm and 46 mm marks (measure from outer sphere surface). Adjust before cure locks.
5. Verify: Total of measured overhangs + sphere outer diameter ≈ 75 mm (sanity check). Overhang tolerance ±0.5 mm acceptable.
6. (Optional) Apply a micro drop of CA at seam points if gaps visible; avoid flooding.
7. After initial set, wick a minimal CA dot at two diametrically opposite points where tube exits sphere if axial slip seems likely (optional).
8. Attach `plunger.stl`:
   - Lightly scuff inside contact surface if glossy.
   - Apply a small ring or 3–4 dots of CA inside plunger socket.
   - Push plunger onto the LONG side (46 mm) tube end until fully seated; a tiny ring of tube should remain visible only if designed so—otherwise flush.
   - Hold until set. Ensure plunger axis aligns with tube (no tilt).

Electrical Checkpoint: (Not applicable – purely mechanical in this step.)

## 6. RIGHT Arm Sphere & Gun (57 mm Tube)

Target overhangs after sphere placement: 17 mm (short) and 30 mm (long).

1. Repeat sphere forming process with remaining two ball halves on 57 mm tube.
2. Position sphere to achieve 17 mm and 30 mm exposed tube lengths; confirm before full cure.
3. Secure seam minimally as in Left Arm (Steps 5.5–5.7 analog).
4. Install `gun_tubes.stl` on the LONG (30 mm) side:
   - Dry fit first; ensure a slight slip fit. Adjust (very light ream) if tight.
   - Apply sparse CA inside the printed part’s bore (avoid ends to prevent squeeze-out).
   - Slide into position leaving a small, even band of tube exposed on both sides of the gun_tubes part (visual symmetry). If design expects flush, adjust accordingly (state assumption here: slight exposure desired per user instruction).
   - Maintain axial alignment until set.

## 7. Shoulder Insertion & Retention (Both Arms – Shared Clamp)

Short tube sides (19 mm plunger / 17 mm gun) go INSIDE `shoulders.stl`; long sides with end effectors remain OUTSIDE.

1. Insert LEFT (plunger) arm short end; seat sphere in left socket—do not release yet.
2. Insert RIGHT (gun) arm short end; seat sphere in right socket.
3. Center Both: Adjust each sphere so overhangs remain correct and end effectors aim neutrally forward. Support assemblies so they don't drop.
4. Place the single `ball_clamp.stl` over BOTH spheres simultaneously (embossed text readable). Ensure clamp lands flat on both socket rims.
5. Start M3 screw by hand 2–3 turns (avoid cross‑thread). Verify clamp not lifting one side.
6. Incremental Tightening: Turn screw until initial contact with both spheres (feel resistance). Test articulation of BOTH arms.
7. Micro‑Adjust: Tighten in 1/16–1/8 turn increments, alternating articulation tests. Stop once both arms have smooth, gently resistive motion—no binding.
8. Final Check: Ensure neither arm is appreciably tighter; if one is stiff and the other loose, back off slightly, re-center clamp, retighten.

## 8. Verification Checklist

| Item | Pass Criteria |
|---|---|
| Left sphere overhangs | 19 mm ±0.5 / 46 mm ±0.5 |
| Right sphere overhangs | 17 mm ±0.5 / 30 mm ±0.5 |
| Plunger alignment | Axis colinear; no wobble |
| Gun_tubes placement | Even narrow tube band both ends (or specified flush) |
| Clamp orientation | Text readable; seated flush across both sockets |
| Screw torque | Both arms pivot smoothly; neither overly tight nor loose |
| Seams | No gaps >0.3 mm; minimal CA residue |

## 9. Troubleshooting

| Symptom | Likely Cause | Remedy |
|---|---|---|
| Sphere drifts before cure | Too little initial friction / excess glue | Hold gently until tack; add micro dot at tube exit after positioning |
| Overhang short/long | Mis-measured from wrong reference (center vs surface) | Reheat gently with hot air (low) if just cured and reposition; otherwise reprint sphere halves |
| Visible seam gap | Print warp or debris | Open gently before full cure; scrape interference; re-glue |
| Plunger/gun_tubes skew | Pressed before square seating | While CA still green (<30s), realign; otherwise debond (acetone / debonder if material supports) and retry |
| Glue bloom (white frosting) | Excess accelerator or humid environment | Reduce accelerator; gently polish with isopropyl + microfiber |
| One arm tight, other loose | Clamp seated unevenly or sphere not fully seated | Loosen slightly, reseat both spheres, retighten gradually |

## 10. Staging for Next Step

- Label left vs right assemblies subtlely on hidden tube portions if future orientation matters.
- Record actual overhang measurements for reference (tolerances OK) in build log.
- Prepare any shoulder mounting brackets or pivot hardware (introduced next step) and confirm clearances with spheres dry-fitted.

## 11. Next Step

Proceed to Step 6 – Skirt Assembly & Shoulder Attachment.

---
Navigation: ← Previous [Step 4 – Neck Stack & Dome Integration](./step4_neck.md) | Next → [Step 6 – Skirt Assembly & Shoulder Attachment](./step6_skirt_assembly.md) | Index ↔ [Assembly Index](./README.md)

Revision: 0.3 (2025-08-23) Updated for single shared clamp & screw retaining both arms simultaneously.
Revision: 0.4 (2025-08-23) Next step renamed to Skirt Assembly & Shoulder Attachment.

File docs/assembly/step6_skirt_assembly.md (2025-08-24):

# Step 6 – Skirt Assembly & Shoulder Attachment

> Objective: Populate the skirt with all hemisphere details (64× `hemi_x65.stl`) using controlled CA glue, then fasten the completed shoulder/arm assembly (from Step 5) onto the skirt with two M3x8 screws.
> Filename Note: The original STL is misnamed `hemi_x65.stl` in the source set (should represent 64 hemispheres). We intentionally retain the on-disk typo here to match the provided files and avoid confusion during printing.
> Prerequisites: Step 5 complete (shoulders with both arms installed & functional). Printed skirt (`skirt.stl`) cleaned of supports; all hemispheres available.

## 1. Parts & Materials

| Category | Item | Qty | Notes |
|---|---|-----|---|
| Printed | skirt.stl | 1 | Base perimeter shell with 64 raised mounting pads |
| Printed | hemi_x65.stl | 64 | Filename retains original typo (prints 1 hemisphere; repeat) |
| Assembly | Shoulder + arms (Step 5) | 1 | To mount on top after hemis installed |
| Hardware | M3x8 screw | 2 | Skirt ↔ shoulder fastening |
| Consumable | CA glue (thin/medium) | As needed | Tiny drops per hemisphere |
| Optional | CA accelerator | Minimal | Use only after placement verified |
| Optional | Painter’s tape / tray | 1 | Stage hemispheres in rows |

Assumption: Skirt includes two internal bosses or through holes aligned to shoulder mounting holes.

## 2. Tools

- Fine tip CA applicator (or micro brush / toothpick)
- #1 or #2 driver (matching M3 screw head)
- Tweezers (hemisphere placement)
- Isopropyl alcohol + lint‑free cloth (surface cleaning)
- Optional: Digital scale (batch verification), clamp pads (if slight warp correction needed)

## 3. Preparation

1. Surface Clean: Wipe skirt exterior with IPA to remove dust/oils; allow to dry fully (improves bond consistency).
2. Hemis Staging: Arrange 64 hemis in a 8×8 or 16×4 grid near workspace; visual count prevents omissions.
3. Test Fit: Place a single hemisphere on several random skirt pads dry—should sit flat without rocking. Lightly deburr any pad high spots or stringing.
4. Orientation: If hemis have a preferred aesthetic (layer seam), face seams consistently (e.g., toward rear) for uniform appearance.
5. Mark Progress: Lightly pencil tick inside skirt after every 8 hemis applied (optional tracking to ensure full count).

## 4. Hemisphere Bonding Process

Recommended adhesive pattern: 1 central micro‑dot OR 3 equally spaced micro‑dots near the pad edge (avoid flooding which can squeeze out and frost surface).

Batch Workflow (repeat until complete):

1. Select 4–8 pads (a manageable batch) and apply CA micro‑dots.
2. Using tweezers, place hemispheres gently—do not slide (sliding can smear glue and tilt). Press straight down for 2–3 seconds.
3. Quick Alignment Check: Ensure each hemisphere is squarely seated (no visible tilt). Adjust within first ~5 seconds if needed.
4. (Optional) Light mist of accelerator held well back (>150 mm) after a full batch is confirmed. Avoid direct puddling.
5. Proceed to next batch; rotate the skirt periodically to keep ergonomic access and reduce accidental contact with uncured glue.

Tips:

- Minimal Glue: Excess increases bloom (white frosting) and cleanup effort.
- Consistent Pressure: Over‑pressing can splay molten edges or create a ring of squeeze‑out.
- Environment: Low humidity reduces blooming; consider gentle airflow (not aimed directly) to speed set without dust.

Completion Check: Count all hemis—should reach 64. Run a fingertip lightly over rows; feel for any loose ones (re‑glue if movement detected).

## 5. Shoulder Assembly Mounting

1. Dry Fit: Place shoulder assembly on top of skirt; confirm mounting holes align with the two internal screw bosses (or holes) in the skirt.
2. Cable Clearance: Ensure any internal wires or harness slack are not pinched between mating surfaces (if wiring already present nearby).
3. Insert First M3x8 Screw: Start by hand 2–3 turns to avoid cross‑threading.
4. Insert Second Screw similarly; only then alternate tightening each until seated—do not overtighten (stop at firm contact + a small snug). Plastic thread caution applies.
5. Rock Test: Gently rock shoulders—no wobble should be present. If wobble exists, verify both screws fully seated and surfaces free of debris.
6. Articulation Re‑Check: Move both arms through range ensuring no hemisphere interferes with lower extremes. If contact occurs, verify overhang lengths or consider subtle chamfer on interfering hemisphere edge (last resort).

## 6. Verification Checklist

| Item | Pass Criteria |
|---|---|
| Hemisphere count | 64 installed; no omissions |
| Bond quality | No loose hemis (light finger pressure test) |
| Glue aesthetics | Minimal/no visible squeeze‑out or frosting |
| Row consistency | Even spacing; consistent seam orientation (if applied) |
| Shoulder seating | Flush contact all around; no gaps >0.3 mm |
| Screw torque | Both M3 snug; no wobble; threads intact |
| Arm clearance | Full motion without striking hemis |

## 7. Troubleshooting

| Symptom | Likely Cause | Remedy |
|---|---|---|
| Hemisphere lifts later | Insufficient glue / oily surface | Clean pad & hemisphere base; reapply tiny CA; hold longer |
| Visible frosting | Excess glue + accelerator humidity | Polish lightly with isopropyl; reduce accelerator usage |
| Tilted hemisphere | Glue set before adjustment | Gently shear off with thin blade; clean pad; re-glue new print |
| Shoulder wobble | Uneven tightening / debris | Loosen both, clean mating face, retighten evenly |
| Screw strips | Over-torque / repeated cycles | Use slightly longer M3 or retrofit heat-set insert |
| Arm collision with hemis | Sphere overhang or hemisphere high | Verify arm build lengths; sand hemisphere crown slightly only if necessary |

## 8. Staging for Next Step

- Document any replacements (re-glued hemis) in build log for future inspection.
- Prepare internal body components / wiring harness channels (next step will begin body integration and routing).

## 9. Next Step

Proceed to Step 7 – Fender Mechanism & Skirt Integration.

---
Navigation: ← Previous [Step 5 – Arm & Shoulder Integration](./step5_shoulders_arms.md) | Next → [Step 7 – Fender Mechanism & Skirt Integration](./step7_fender_mechanism.md) | Index ↔ [Assembly Index](./README.md)

Revision: 0.1 (2025-08-23) Initial draft of skirt assembly & shoulder attachment.
Revision: 0.2 (2025-08-23) Updated next step to Fender Mechanism & Skirt Integration.
Revision: 0.3 (2025-08-24) Corrected hemisphere filename (hemi_x64) and standardized objective wording.
Revision: 0.4 (2025-08-24) Reverted to on-disk typo `hemi_x65.stl` with explanatory note (cannot rename file in set).

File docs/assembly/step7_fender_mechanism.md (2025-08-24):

# Step 7 – Fender Mechanism & Skirt Integration

> Objective: Assemble the fender cam mechanism (N20 motor, dual cams, pushrods, clamp), fasten motor mount to the fender, then stack the skirt/shoulder assembly ensuring arm ends seat into pushrod holes, securing the skirt to the fender.
> Prerequisites: Step 6 complete (skirt populated & shoulders attached). All printed mechanical parts present; N20 motor tested (brief spin) and wire leads accessible.

## 1. Parts & Materials

| Category | Item | Qty | Notes |
|---|---|-----|---|
| Printed | fender.stl | 1 | Base platform receiving motor mount & skirt |
| Printed | motor_mount.stl | 1 | Mounting interface (3 screws to fender) |
| Printed | cam_1.stl | 1 | Primary cam with shaft & flat reference (embossed line) |
| Printed | cam_2.stl | 1 | Secondary cam (sleeves over cam_1) |
| Printed | cam_cap.stl | 1 | Retains cam_2 axially (screwed) |
| Printed | pushrod_a.stl | 1 | Has distal hole that must face LEFT when installed |
| Printed | pushrod_b.stl | 1 | Upper hole must face RIGHT when installed |
| Printed | cam_motor_clamp.stl | 1 | Guides pushrods; clamps motor to mount (2 screws) |
| Assembly | Skirt + shoulders + arms (Step 6) | 1 | To stack over fender later |
| Electronic | N20 gearmotor | 1 | Shaft clean & free of burrs |
| Hardware | M3x8 screw | 3 | Motor mount → fender |
| Hardware | M3x8 screw | 1 | Cam cap → cam_1 shaft retention |
| Hardware | M3x8 screw | 2 | cam_motor_clamp → motor_mount |
| Hardware | M3x8 screw | 2 | Skirt → fender final attachment |
| Optional | Thread locker (low strength) | Trace | On cam cap screw if vibration expected |

Assumption: All M3 holes are printed undersized for thread forming; no inserts required.

## 2. Tools

- #1/#2 Phillips or hex driver (per screw head)
- Tweezers / needle-nose pliers (position pushrods)
- Small flat file (deburr cam shaft flat, if needed)
- Multimeter / bench supply (brief motor test)

## 3. Preparation

1. Test Motor: Apply low voltage (e.g., 3–5 V) momentarily—confirm smooth rotation, note direction for wiring later.
2. Inspect Cam Parts: Ensure cam_1 shaft flat has a crisp edge (embossed line indicates flat orientation). Lightly scrape artifacts.
3. Dry Fit: Slide cam_1 (no pushrods yet) onto motor shaft; verify firm friction fit without splitting. Remove.
4. Confirm Pushrod Orientation: Identify pushrod_a (later hole points LEFT) and pushrod_b (upper hole toward RIGHT). Mark lightly with pencil for quick reference.
5. Organize Screws: Separate 3+1+2+2 sets to avoid miscount during sequence.

## 4. Motor Mount to Fender

1. Position motor_mount on top of fender aligning the three mounting holes.
2. Insert the three M3x8 screws by hand 1–2 turns each (avoid cross‑threading).
3. Tighten incrementally in a triangle pattern until snug (do not over‑torque). Mount should sit flush—no rocking.

## 5. Cam & Pushrod Stack Assembly

Follow exact orientation—reversal will invert motion or cause interference.

1. Install cam_1: Align its internal flat to the motor shaft flat (embossed line on cam_1 indicates flat). Press fully home—shoulder flush.
2. Place pushrod_b onto cam_1: Seat over its eccentric post ensuring the UPPER hole of the pushrod faces to the RIGHT side of the assembly.
3. Slide cam_2 over the shaft of cam_1: Ensure it seats fully without pinching pushrod_b.
4. Add pushrod_a onto cam_2 (eccentric feature) so its distal hole (at the end) points to the LEFT side.
5. Fit cam_cap over the exposed end of cam_1 shaft, capturing cam_2 and pushrods.
6. Insert and tighten a single M3x8 into cam_cap (threading into cam_1). Tighten just until secure; optional trace of low‑strength thread locker if high vibration expected.

Inspection: Both pushrods should articulate independently on their respective cam lobes without binding when motor shaft is turned by hand.

## 6. Pushrod Channel Alignment (Clamp Installation)

1. Orient cam_motor_clamp so its slots align over both pushrods.
2. Gently slide the TWO pushrods through their respective slits/slots in the clamp. Ensure no twisting; rods should move freely vertically when cam rotated.
3. Keep clamp hovering (do not fasten yet) while confirming rods are not pre‑loaded sideways.

## 7. Motor & Clamp Fastening

1. Place N20 motor (with assembled cams & pushrods + loose clamp) into motor_mount pocket.
2. Lower cam_motor_clamp into final seated position atop motor_mount aligning its two screw holes.
3. Insert both M3x8 screws by hand 2–3 turns, then tighten alternately until snug (even pressure). Do not overtighten—avoid distorting clamp.
4. Rotate motor shaft manually (by turning accessible cam) through a full revolution—verify smooth pushrod reciprocation and absence of rubbing on clamp edges. Correct by slight pushrod centering if needed.

## 8. Skirt Stacking & Arm Engagement

Critical: Arm ends must insert into pushrod holes before securing skirt.

1. Position the completed skirt/shoulder assembly above the fender mechanism.
2. Lower carefully while guiding LEFT and RIGHT arm tube ends into the corresponding upper holes of pushrod_b (RIGHT‑facing hole) and pushrod_a (LEFT‑facing hole) respectively. (Ensure previous orientation steps preserved correct sides.)
3. Once both arm ends are partially inserted, lower skirt fully until its mounting holes align with the fender holes.
4. Insert two M3x8 screws (skirt → fender) finger‑tight first.
5. Confirm both arms still seated in pushrod holes (no binding) by gently oscillating each arm.
6. Tighten screws to snug; re‑test articulation by rotating motor slightly by hand—observe synchronized pushrod/arm motion.

## 9. Verification Checklist

| Item | Pass Criteria |
|---|---|
| Motor mount fastening | 3 screws snug; mount flush |
| Cam_1 seating | Fully home; no axial wobble |
| Pushrod_b orientation | Upper hole faces RIGHT |
| Pushrod_a orientation | Distal hole points LEFT |
| Cam_2 & cap retention | Cap secure; no axial play; screw snug |
| Pushrod travel | Smooth through full manual rotation; no clamp rub |
| Arm engagement | Both arm ends seated in pushrod holes; move with cams |
| Skirt attachment | 2 screws snug; no gap or rocking |
| Manual actuation | Hand rotation produces expected alternating arm motion |

## 10. Troubleshooting

| Symptom | Likely Cause | Remedy |
|---|---|---|
| Pushrod binds mid travel | Misaligned clamp or burr in slot | Loosen clamp, deburr slot edges, re-center rods |
| Arm slips out of pushrod | Incomplete insertion / wrong orientation | Re-seat with slight downward pressure; verify hole facing correct side |
| Cam stack axial play | Cap screw loose | Retighten; add low-strength thread locker |
| Uneven arm motion | Reversed pushrods or swapped sides | Disassemble pushrod stage; correct orientations per steps 5.2 & 5.4 |
| Motor stalls under light load | Excess friction / overtight clamp | Loosen clamp screws 1/8 turn; check for rubbing |
| Noise / chatter | Dry plastic cam interface | Very light PTFE dry lube on cam lobes (avoid motor) |

## 11. Staging for Next Step

- Plan wiring path from motor leads toward control board; leave service loop for maintenance.
- Prepare any limit switch or sensor hardware if later automation is intended.

## 12. Next Step

Proceed to Step 8 – Wiring Harness Integration & Electronics Mounting (forthcoming).

---
Navigation: ← Previous [Step 6 – Skirt Assembly & Shoulder Attachment](./step6_skirt_assembly.md) | Next → [Step 8 – Wiring Harness Integration & Electronics Mounting](./step8_wiring_electronics.md) | Index ↔ [Assembly Index](./README.md)

Revision: 0.1 (2025-08-23) Initial draft of fender mechanism & skirt integration.
Revision: 0.2 (2025-08-24) Updated navigation to active Step 8 link.

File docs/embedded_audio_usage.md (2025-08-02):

# Embedded Audio System Usage

> **Copyright Notice**: This project is for educational purposes only. Users are responsible for ensuring they have appropriate rights to any audio content used. The system provides tools for audio conversion but does not include copyrighted content.

## Overview

The project includes a complete embedded audio system that converts audio files into PCM C++ headers for direct I2S playback. Audio data is preprocessed and committed to the repository for GitHub Actions compatibility.

## Audio System Features

✅ **Pre-processed PCM Audio** - No real-time decoding required  
✅ **GitHub Actions Ready** - No Python dependencies for builds  
✅ **24 Audio Files** - Complete Dalek sound library included  
✅ **Optimized Format** - 22.05kHz mono 16-bit for memory efficiency  
✅ **Direct I2S Output** - Zero CPU overhead during playback  

## Quick Start

### 1. Using Existing Audio (Recommended)

The repository includes 24 pre-converted audio files ready for use:

```cpp
#include "AudioController.h"
#include "audio/audio_index.h"

// Initialize audio controller
AudioController::Config config;
config.bclkPin = 18;        // I2S Bit Clock
config.lrclkPin = 19;       // I2S Left/Right Clock  
config.dinPin = 20;         // I2S Data Input
config.sampleRate = 22050;  // Sample rate
config.bitsPerSample = 16;  // 16-bit PCM

AudioController audioController(config);
audioController.initialize();

// Play audio file by index
audioController.playAudio(Audio::AudioIndex::AUDIO_00001);

// Or get file info first
auto audioFile = Audio::getAudioFile(Audio::AudioIndex::AUDIO_00001);
if (audioFile) {
    printf("Playing: %s (%.2f seconds)\n", 
           audioFile->name,
           (float)audioFile->sample_count / audioFile->sample_rate);
    
    audioController.playPCMAudioData(
        audioFile->data,
        audioFile->sample_count,
        audioFile->sample_rate,
        audioFile->channels
    );
}
```

### 2. Adding New Audio Files (Development Only)

**Prerequisites** (one-time setup):
```bash
pip install librosa soundfile numpy==2.1.0
```

**Conversion Process**:
1. Place MP3 files in `misc/` directory with numbered names (`00025.mp3`, etc.)
2. Run conversion script:
   ```powershell
   # PowerShell
   .\tools\convert_audio.ps1
   
   # Command Prompt  
   tools\convert_audio.bat
   
   # Python directly
   python tools/audio_to_pcm_header.py misc include/audio --pattern "*.mp3"
   ```
3. Commit the generated `.h` files to git (MP3 files are excluded by `.gitignore`)
4. Rebuild project

AudioController audio(config);

// Play a specific audio file
audio.playAudio(AudioIndex::AUDIO_00001);

// Set volume (0.0 to 1.0)
audio.setVolume(0.8f);
```

## System Architecture

### Generated Files

For each MP3 file `XXXXX.mp3`, the system generates:
- `include/audio/XXXXX.h` - Contains the audio data as a byte array
- `include/audio/audio_index.h` - Registry of all available audio files

### Audio File Registry

The `audio_index.h` provides:
- `AUDIO_FILES[]` - Array of AudioFile structs with name, data pointer, and size
- `AUDIO_FILE_COUNT` - Total number of available files
- `AudioIndex` enum - Strongly typed indices for each audio file

### Hardware Configuration

The audio system uses PIO (Programmable I/O) to implement I2S output:
- **GPIO 18**: I2S Clock (SCK)
- **GPIO 19**: I2S Data (SD) 
- **GPIO 20**: I2S Word Select (WS/LRCK)

Connect these to an I2S DAC or audio codec for output.

## File Size Considerations

- Audio files are embedded directly in flash memory
- Large MP3 files will increase the program size
- The RP2040 has 2MB of flash memory total
- Current 24 audio files use approximately 2.2MB total

## Git Configuration

The system is configured to:
- ✅ Include generated `.h` files in version control
- ❌ Exclude source `.mp3` files from version control (via `.gitignore`)

This means the generated headers are committed, but the source MP3 files are not tracked.

## Build Integration

The audio system is automatically included in the build:
- Headers are in the include path
- AudioController.cpp is compiled
- No additional CMake configuration needed

## Troubleshooting

### Compilation Errors
If you get "missing terminating character" errors:
1. Delete all files in `include/audio/`
2. Re-run `python tools\mp3_to_header.py misc include\audio`
3. Clean and rebuild: `ninja clean && ninja`

### Memory Issues
If you run out of flash memory:
1. Remove unused MP3 files from `misc/`
2. Use shorter/compressed audio clips
3. Consider using lower bitrate MP3s

## Example: Dalek Voice System

```cpp
// Play the iconic "Exterminate!" sound
if (gamepad.buttonPressed(BUTTON_A)) {
    audio.playAudio(AudioIndex::AUDIO_00001); // Exterminate
}

// Play movement sounds
if (gamepad.leftStick.x != 0 || gamepad.leftStick.y != 0) {
    audio.playAudio(AudioIndex::AUDIO_00005); // Movement sound
}
```

This embedded audio system provides a robust foundation for the animatronic Dalek's sound effects, allowing for rich audio feedback without external dependencies.

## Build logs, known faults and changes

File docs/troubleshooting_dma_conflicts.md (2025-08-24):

# Troubleshooting: DMA Channel Conflicts

## Problem Description

**Symptoms:**
- Runtime panic: `"DMA channel X is already claimed"`
- LED staying solid instead of breathing during Bluetooth pairing
- Gamepad controller not pairing
- System hangs or crashes during audio initialization

## Root Cause

The pico-extras I2S library (`audio_i2s_setup()`) expects to manage its own DMA channels and PIO state machines internally. When the application pre-claims these resources, it creates conflicts when the library attempts to claim the same resources.

## The Fix: Resource Discovery Pattern

### ❌ Problematic Approach (Pre-claiming)

```cpp
// DON'T: Pre-claim resources permanently
int dma_channel = dma_claim_unused_channel(true);  // true = claim permanently
uint pio_sm = pio_claim_unused_sm(pio, true);      // true = claim permanently

// Library fails when it tries to claim the same resources
audio_i2s_config_t config = { /* ... */ };
audio_i2s_setup(&format, &config);  // ❌ PANIC: DMA channel already claimed
```

### ✅ Solution (Resource Discovery)

```cpp
// DO: Discover available resources without claiming them permanently
int dma_channel = dma_claim_unused_channel(false);  // false = just find available
uint pio_sm = pio_claim_unused_sm(pio, false);      // false = just find available

// Immediately release the resources for the library to use
dma_channel_unclaim(dma_channel);
pio_sm_unclaim(pio, pio_sm);

// Configure the library to use the discovered resources
audio_i2s_config_t config = {
    .data_pin = 34,
    .clock_pin_base = 32,
    .dma_channel = dma_channel,    // Library will claim this internally
    .pio_sm = pio_sm               // Library will claim this internally
};

// Library successfully claims and manages resources internally
audio_i2s_setup(&format, &config);  // ✅ SUCCESS
```

## Implementation Details

### AudioController::initialize() Method

The fix is implemented in the `AudioController::initialize()` method:

```cpp
bool AudioController::initialize() {
    // Resource discovery for DMA channels
    int dma_channel = dma_claim_unused_channel(false);
    if (dma_channel < 0) {
        printf("ERROR: No available DMA channels\n");
        return false;
    }
    dma_channel_unclaim(dma_channel);  // Release immediately
    
    // Resource discovery for PIO state machines
    PIO pio = pio1;
    uint pio_sm = pio_claim_unused_sm(pio, false);
    if (pio_sm == -1) {
        pio = pio0;  // Fallback to PIO0
        pio_sm = pio_claim_unused_sm(pio, false);
        if (pio_sm == -1) {
            printf("ERROR: No available PIO state machines\n");
            return false;
        }
    }
    pio_sm_unclaim(pio, pio_sm);  // Release immediately
    
    // Configure I2S with discovered resources
    audio_i2s_config_t config = {
        .data_pin = 34,
        .clock_pin_base = 32,
        .dma_channel = dma_channel,
        .pio_sm = pio_sm
    };
    
    // Let pico-extras library manage resources internally
    return audio_i2s_setup(&format, &config);
}
```

## Why This Works

1. **Resource Discovery**: Find available DMA channels and PIO state machines without permanently claiming them
2. **Immediate Release**: Unclaim the resources immediately so they're available for the library
3. **Library Management**: Let the pico-extras I2S library claim and manage the resources internally
4. **No Conflicts**: Avoids the "double claiming" that caused the original panic

## Verification

After applying the fix, you should see:

### ✅ Expected Behavior
- LED shows breathing pattern during Bluetooth pairing
- Gamepad controller pairs successfully  
- No "DMA channel already claimed" panics
- Audio system initializes without errors

### 🔍 Debug Output
```
AudioController: Discovered DMA channel 2
AudioController: Discovered PIO1 state machine 0
AudioController: I2S setup successful
Audio initialized successfully
```

## Related Systems

This fix resolves conflicts that were also affecting:

- **BluePad32 Bluetooth System**: No longer blocked by audio resource conflicts
- **LED Controller**: Can now properly initialize and show breathing patterns
- **Motor Controller**: Unaffected but benefits from stable system initialization

## Prevention

When integrating other libraries that manage hardware resources:

1. **Check Library Documentation**: Understand how the library manages DMA, PIO, and other resources
2. **Use Discovery Pattern**: Find available resources without permanently claiming them
3. **Let Libraries Manage**: Allow libraries to handle their own resource lifecycle
4. **Test Integration**: Verify that multiple subsystems can coexist without conflicts

## Additional Resources

- [Pico SDK Hardware Claims Documentation](https://raspberrypi.github.io/pico-sdk-doxygen/group__hardware__claim.html)
- [Pico Extras I2S Library Source](https://github.com/raspberrypi/pico-extras/tree/master/src/rp2_common/pico_audio_i2s)
- [DMA Channel Management Best Practices](https://raspberrypi.github.io/pico-sdk-doxygen/group__hardware__dma.html)

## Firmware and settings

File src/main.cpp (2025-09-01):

#include <stdio.h>
#include <cmath>
#include <algorithm>
#include "pico/stdlib.h"
#include "GamepadController.h"
#include "AudioController.h"
#include "SimpleLED.h"
#include "MotorController.h"
#include "audio/00001.h"  // Boot sound
#include "MosfetDriver.h"

// Guard optional CYW43 include so builds succeed even if headers aren't present
#if defined(__has_include)
#  if __has_include("pico/cyw43_arch.h")
#    include "pico/cyw43_arch.h"
#    define EX_HAS_CYW43 1
#  else
#    define EX_HAS_CYW43 0
#  endif
#else
#  define EX_HAS_CYW43 0
#endif

using namespace Exterminate;
using namespace Exterminate::SimpleLED;

int main() {
    stdio_init_all();
    
    // Small delay for system initialization
    sleep_ms(1000);
    
    printf("===========================================\n");
    printf("Exterminate Dalek - Full System Starting\n");
    printf("===========================================\n");
    
    // Initialize LED status controller for blue eye stalk LED
    LEDStatusController eyeLED;
    // Relocated to a higher GPIO (bottom edge exposed) per hardware mounting requirement.
    // Moved out of the 35-43 range to avoid conflicts with external wiring.
    // Use a high GPIO in the 44-47 range by default.
    const unsigned int BLUE_LED_PIN = 44; // Blue LED for eye stalk status (previously 36)
    
    if (eyeLED.initialize(BLUE_LED_PIN)) {
        printf("Blue eye LED initialized on GPIO %u\n", BLUE_LED_PIN);
    } else {
        printf("WARNING: Failed to initialize blue eye LED on GPIO %u\n", BLUE_LED_PIN);
        printf("Continuing without LED status indication...\n");
    }
    
    // Initialize gamepad controller first
    GamepadController& gamepadController = GamepadController::getInstance();
    
    // Set the LED controller for automatic status updates
    if (eyeLED.isInitialized()) {
        gamepadController.setLEDController(&eyeLED);
    }
    
    if (!gamepadController.initialize()) {
        printf("ERROR: Failed to initialize gamepad controller!\n");
        printf("Make sure you're using a Pico W board with Bluetooth support.\n");
        return -1;
    }

    printf("GamepadController initialized successfully.\n");
    
    // Initialize and test audio system
    AudioController audio;
    if (audio.initialize()) {
        printf("Audio initialized successfully\n");
        
        // Set the audio controller for gamepad button controls after audio init
        gamepadController.setAudioController(&audio);
        
        // Play boot sound
        printf("Playing boot sound...\n");
        if (audio.playAudio(Audio::AudioIndex::AUDIO_00001)) {
            printf("Boot sound started successfully\n");
            
            // Two external LEDs driven by audio intensity via PWM (skip onboard LED)
            // Moved to higher GPIO range (35-47) to avoid mechanical blockage and wiring congestion.
            // Move external audio LEDs out of 35-43 into a lower header-friendly range (13-18)
            const unsigned extLedPins[] = {14, 15}; // Red audio LEDs (moved from 37,38) -> now using 14,15
            bool pwmOk[2] = {false, false};
            for (int i = 0; i < 2; ++i) {
                pwmOk[i] = Exterminate::SimpleLED::initializePwmPin(extLedPins[i], /*wrap*/255, /*clkdiv*/4.0f);
                printf("External LED on GPIO %u %s\n", extLedPins[i], pwmOk[i] ? "initialized with PWM." : "failed PWM init!");
            }

            bool redLedsWorking = (pwmOk[0] || pwmOk[1]);

            if (redLedsWorking) {
                // Periodically update LED brightness from audio intensity
                static repeating_timer_t ledTimer;
                struct LedTimerCtx { Exterminate::AudioController* audio; unsigned pins[2]; int count; float displayLevel; };
                static LedTimerCtx ctx{ &audio, {extLedPins[0], extLedPins[1]}, 2, 0.0f };
                add_repeating_timer_ms(20, [](repeating_timer_t* rt) -> bool {
                    auto* c = static_cast<LedTimerCtx*>(rt->user_data);
                    float intensity = 0.0f;
                    if (c && c->audio) {
                        // Apply natural decay to audio intensity for LED effects
                        c->audio->decayAudioIntensity();
                        intensity = c->audio->getAudioIntensity();
                    }
                    // Increase contrast: deadzone + gamma + peak hold
                    const float deadzone = 0.20f;
                    float adj = (intensity - deadzone) * (1.0f / (1.0f - deadzone));
                    if (adj < 0.0f) adj = 0.0f;
                    if (adj > 1.0f) adj = 1.0f;
                    const float gamma = 2.5f;
                    float b = adj <= 0.0f ? 0.0f : static_cast<float>(std::pow(adj, gamma));
                    c->displayLevel = std::max(b, c->displayLevel * 0.90f);
                    for (int i = 0; i < c->count; ++i) {
                        Exterminate::SimpleLED::setBrightnessPin(c->pins[i], c->displayLevel);
                    }
                    return true; // keep repeating
                }, &ctx, &ledTimer);
                printf("Red LEDs configured to react to audio intensity\n");
            } else {
                printf("No external LEDs initialized. Check pins/wiring.\n");
            }
            
            // Store LED status for later reporting
            static bool s_redLedsWorking = redLedsWorking;
        } else {
            printf("Failed to start boot sound\n");
        }
    } else {
        printf("Audio initialization failed!\n");
    }
    
    // Configure the motor controller for the DRV8833
    static MotorController::Config motorConfig{
        .leftMotorPin1 = 6,  // AIN1
        .leftMotorPin2 = 7,  // AIN2
        .rightMotorPin1 = 27, // BIN1
        .rightMotorPin2 = 26, // BIN2
        .pwmFrequency = 20000 // 20 kHz
    };

    static MotorController motorController(motorConfig);

    if (motorController.initialize()) {
        printf("Motor controller initialized successfully.\n");
    } else {
        printf("Failed to initialize motor controller.\n");
        return -1;
    }

    // Set the MotorController for tank-style control using existing gamepadController
    gamepadController.setMotorController(&motorController);

    // Instantiate and register MOSFET driver (use a free GPIO pin)
    // Move MOSFET control out of 35-43 to the high GPIO region (44-47)
    const uint8_t MOSFET_CONTROL_PIN = 45; // MOSFET gate control (moved from 43)
    static Exterminate::MosfetDriver mosfetDriver(MOSFET_CONTROL_PIN);
    mosfetDriver.initialize();
    gamepadController.setMosfetDriver(&mosfetDriver);

    // Start the gamepad event loop
    gamepadController.startEventLoop();
    
    printf("\n");
    printf("===========================================\n");
    printf("System Status:\n");
    printf("- Blue Eye LED: %s\n", eyeLED.isInitialized() ? "Active (breathing = pairing mode)" : "Disabled");
    printf("- Red Audio LEDs: %s\n", audio.isInitialized() ? "Active (react to audio)" : "Disabled");
    printf("- Audio System: %s\n", audio.isInitialized() ? "Ready" : "Failed");
    printf("- Motor Control: %s\n", motorController.isInitialized() ? "Ready" : "Failed");
    printf("- Gamepad Controller: Ready for connections\n");
    printf("\n");
    printf("LED Status Indicators:\n");
    printf("- Blue LED Breathing: Pairing mode (ready for connections)\n");
    printf("- Blue LED Solid: Controller paired and ready\n");
    printf("- Blue LED Fast blink: Error state\n");
    printf("- Blue LED Slow blink: Initializing or connecting\n");
    printf("- Red LEDs: Brightness follows audio intensity\n");
    printf("\n");
    printf("Instructions:\n");
    printf("1. Put your gamepad into pairing mode\n");
    printf("2. All gamepad inputs will be logged to this UART console\n");
    printf("3. Audio Controls:\n");
    printf("   - A Button: Trigger sound bite\n");
    printf("   - Red LEDs will react to audio playback\n");
    printf("4. Use Ctrl+C to stop the program if needed\n");
    printf("\n");
    printf("Starting BluePad32 event loop...\n");
    printf("LED updates and system operation handled automatically.\n");
    printf("===========================================\n");
    
    // Start the gamepad event loop (this blocks and doesn't return)
    // All LED updates, audio, and motor control are handled via callbacks
    gamepadController.startEventLoop();
    
    // This line should never be reached
    printf("Event loop ended unexpectedly!\n");
    return 0;
}

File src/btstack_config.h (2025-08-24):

#ifndef _PICO_BTSTACK_BTSTACK_CONFIG_H
#define _PICO_BTSTACK_BTSTACK_CONFIG_H

// Copy & paste from, with some custom changes:
// https://github.com/raspberrypi/pico-examples/blob/master/pico_w/bt/config/btstack_config.h

// BTstack features that can be enabled
#define ENABLE_LOG_INFO
#define ENABLE_LOG_ERROR
#define ENABLE_PRINTF_HEXDUMP
#define ENABLE_SCO_OVER_HCI

#ifdef ENABLE_BLE
#define ENABLE_GATT_CLIENT_PAIRING
#define ENABLE_L2CAP_LE_CREDIT_BASED_FLOW_CONTROL_MODE
#define ENABLE_LE_CENTRAL
#define ENABLE_LE_DATA_LENGTH_EXTENSION
#define ENABLE_LE_PERIPHERAL
#define ENABLE_LE_PRIVACY_ADDRESS_RESOLUTION
#define ENABLE_LE_SECURE_CONNECTIONS
#else
#error "BP32: ENABLE_BLE should be defined"
#endif

#ifdef ENABLE_CLASSIC
#define ENABLE_L2CAP_ENHANCED_RETRANSMISSION_MODE
#define ENABLE_GOEP_L2CAP
#else
#error "BP32: ENABLE_CLASSIC should be defined"
#endif

#if defined(ENABLE_CLASSIC) && defined(ENABLE_BLE)
#define ENABLE_CROSS_TRANSPORT_KEY_DERIVATION
#endif

// BTstack configuration. buffers, sizes, ...
#define HCI_OUTGOING_PRE_BUFFER_SIZE 4
#define HCI_ACL_PAYLOAD_SIZE (1691 + 4)
#define HCI_ACL_CHUNK_SIZE_ALIGNMENT 4
#define MAX_NR_AVDTP_CONNECTIONS 1
#define MAX_NR_AVDTP_STREAM_ENDPOINTS 1
#define MAX_NR_AVRCP_CONNECTIONS 2
#define MAX_NR_BNEP_CHANNELS 1
#define MAX_NR_BNEP_SERVICES 1
#define MAX_NR_BTSTACK_LINK_KEY_DB_MEMORY_ENTRIES 2
#define MAX_NR_GATT_CLIENTS 4
#define MAX_NR_HCI_CONNECTIONS 4
#define MAX_NR_HID_HOST_CONNECTIONS 4
#define MAX_NR_HIDS_CLIENTS 4
#define MAX_NR_HFP_CONNECTIONS 1
#define MAX_NR_HSP_CONNECTIONS 1
#define MAX_NR_L2CAP_CHANNELS 16
#define MAX_NR_L2CAP_SERVICES 8
#define MAX_NR_PBAP_CONNECTIONS 1
#define MAX_NR_RFCOMM_CHANNELS 8
#define MAX_NR_RFCOMM_MULTIPLEXERS 8
#define MAX_NR_RFCOMM_SERVICES 8
#define MAX_NR_SERVICE_RECORD_ITEMS 4
#define MAX_NR_SM_LOOKUP_ENTRIES 3
#define MAX_NR_WHITELIST_ENTRIES 16
#define MAX_NR_LE_DEVICE_DB_ENTRIES 16

// Limit number of ACL/SCO Buffer to use by stack to avoid cyw43 shared bus issues
#define MAX_NR_CONTROLLER_ACL_BUFFERS 3
#define MAX_NR_CONTROLLER_SCO_PACKETS 3

// Enable and configure HCI Controller to Host Flow Control to avoid cyw43 shared bus issues
#define ENABLE_HCI_CONTROLLER_TO_HOST_FLOW_CONTROL
#define HCI_HOST_ACL_PACKET_LEN 1024
#define HCI_HOST_ACL_PACKET_NUM 2
#define HCI_HOST_SCO_PACKET_LEN 120
#define HCI_HOST_SCO_PACKET_NUM 2

// Link Key DB and LE Device DB using TLV on top of Flash Sector interface
#define NVM_NUM_DEVICE_DB_ENTRIES 16
#define NVM_NUM_LINK_KEYS 16

// We don't give btstack a malloc, so use a fixed-size ATT DB.
#define MAX_ATT_DB_SIZE 512

// BTstack HAL configuration
#define HAVE_EMBEDDED_TIME_MS

// map btstack_assert onto Pico SDK assert()
#define HAVE_ASSERT

// Some USB dongles take longer to respond to HCI reset (e.g. BCM20702A0)
#define HCI_RESET_RESEND_TIMEOUT_MS 1000

#define ENABLE_SOFTWARE_AES128
#define ENABLE_MICRO_ECC_FOR_LE_SECURE_CONNECTIONS

#endif

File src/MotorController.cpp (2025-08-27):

#include "MotorController.h"
#include <algorithm>
#include <cmath>
#include <cstdio>

namespace Exterminate {

MotorController::MotorController(const Config& config)
    : config_(config)
    , initialized_(false)
    , leftPwmSlice_(0)
    , rightPwmSlice_(0)
    , leftPwmChannelA_(0)
    , leftPwmChannelB_(0)
    , rightPwmChannelA_(0)
    , rightPwmChannelB_(0)
{
    // Constructor only stores configuration - actual initialization happens in initialize()
}

MotorController::~MotorController()
{
    if (initialized_) {
        stopAllMotors();
        
        // Disable PWM slices
        pwm_set_enabled(leftPwmSlice_, false);
        pwm_set_enabled(rightPwmSlice_, false);
        
        // Reset GPIO pins to input mode
        gpio_set_function(config_.leftMotorPin1, GPIO_FUNC_SIO);
        gpio_set_function(config_.leftMotorPin2, GPIO_FUNC_SIO);
        gpio_set_function(config_.rightMotorPin1, GPIO_FUNC_SIO);
        gpio_set_function(config_.rightMotorPin2, GPIO_FUNC_SIO);
        
        gpio_set_dir(config_.leftMotorPin1, GPIO_IN);
        gpio_set_dir(config_.leftMotorPin2, GPIO_IN);
        gpio_set_dir(config_.rightMotorPin1, GPIO_IN);
        gpio_set_dir(config_.rightMotorPin2, GPIO_IN);
    }
}

bool MotorController::initialize()
{
    if (initialized_) {
        printf("DEBUG: MotorController already initialized.\n");
        return true;
    }

    printf("DEBUG: Initializing MotorController...\n");
    printf("DEBUG: Pin configuration - Left: GPIO%u,GPIO%u | Right: GPIO%u,GPIO%u\n",
           config_.leftMotorPin1, config_.leftMotorPin2, 
           config_.rightMotorPin1, config_.rightMotorPin2);

    try {
        // Configure PWM for all motor pins
        printf("DEBUG: Configuring PWM for motor pins...\n");
        leftPwmSlice_ = configurePwmPin(config_.leftMotorPin1);
        configurePwmPin(config_.leftMotorPin2);
        rightPwmSlice_ = configurePwmPin(config_.rightMotorPin1);
        configurePwmPin(config_.rightMotorPin2);

        printf("DEBUG: PWM slices - Left: %u, Right: %u\n", leftPwmSlice_, rightPwmSlice_);

        // Get PWM channels for each pin
        leftPwmChannelA_ = pwm_gpio_to_channel(config_.leftMotorPin1);
        leftPwmChannelB_ = pwm_gpio_to_channel(config_.leftMotorPin2);
        rightPwmChannelA_ = pwm_gpio_to_channel(config_.rightMotorPin1);
        rightPwmChannelB_ = pwm_gpio_to_channel(config_.rightMotorPin2);

        printf("DEBUG: PWM channels - Left: %u,%u | Right: %u,%u\n",
               leftPwmChannelA_, leftPwmChannelB_, rightPwmChannelA_, rightPwmChannelB_);

    // Set PWM to requested frequency: f = sys_clk / (clkdiv * (wrap + 1))
    // Prefer clkdiv = 1 for maximum resolution and compute wrap accordingly
    constexpr uint32_t sys_clk_hz = 125000000; // 125 MHz default
    uint32_t target = config_.pwmFrequency == 0 ? 20000 : config_.pwmFrequency; // default 20kHz
    if (target < 100) target = 100; // avoid extremely low frequencies
    uint32_t wrap = (sys_clk_hz / target);
    if (wrap == 0) wrap = 1;
    if (wrap > 0) wrap -= 1;
    if (wrap > 65535u) wrap = 65535u;

        printf("DEBUG: PWM setup - Target freq: %uHz, Wrap: %u\n", target, wrap);

    // Initialize PWM slices with proper configuration (like Pimoroni examples)
    pwm_config cfg = pwm_get_default_config();
    pwm_config_set_clkdiv(&cfg, 1.0f);
    pwm_config_set_wrap(&cfg, static_cast<uint16_t>(wrap));
    
    // Apply configuration and start PWM
    pwm_init(leftPwmSlice_, &cfg, true);
    pwm_init(rightPwmSlice_, &cfg, true);

        // Start with motors stopped
        printf("DEBUG: Stopping all motors initially...\n");
        stopAllMotors();

        initialized_ = true;
        printf("DEBUG: MotorController initialization successful!\n");
        return true;
    }
    catch (...) {
        printf("ERROR: MotorController initialization failed with exception!\n");
        return false;
    }
}

void MotorController::setMotorSpeed(Motor motor, float speed)
{
    if (!initialized_) {
        printf("DEBUG: MotorController not initialized! Cannot set motor speed.\n");
        return;
    }

    // Debug: Log all motor speed commands
    printf("DEBUG: setMotorSpeed - Motor=%s, Speed=%.3f\n", 
           motor == Motor::LEFT ? "LEFT" : "RIGHT", speed);

    // Constrain speed to valid range
    speed = constrain(speed, -1.0f, 1.0f);

    uint8_t pin1, pin2;
    
    if (motor == Motor::LEFT) {
        pin1 = config_.leftMotorPin1;
        pin2 = config_.leftMotorPin2;
        printf("DEBUG: Left motor pins - Pin1=%u (GPIO%u), Pin2=%u (GPIO%u)\n", pin1, pin1, pin2, pin2);
    } else {
        pin1 = config_.rightMotorPin1;
        pin2 = config_.rightMotorPin2;
        printf("DEBUG: Right motor pins - Pin1=%u (GPIO%u), Pin2=%u (GPIO%u)\n", pin1, pin1, pin2, pin2);
    }

    if (speed > 0.0f) {
        // Forward direction (now both motors use what was previously 'reverse' logic)
        if (motor == Motor::LEFT) {
            printf("DEBUG: Motor forward (LEFT now reverse logic) - GPIO%u=%.3f, GPIO%u=0.0\n", pin1, speed, pin2);
            setPwmDutyCycle(pin1, speed);
            setPwmDutyCycle(pin2, 0.0f);
        } else {
            printf("DEBUG: Motor forward (RIGHT now reverse logic) - GPIO%u=0.0, GPIO%u=%.3f\n", pin1, pin2, speed);
            setPwmDutyCycle(pin1, 0.0f);
            setPwmDutyCycle(pin2, speed);
        }
    } else if (speed < 0.0f) {
        // Reverse direction (now both motors use what was previously 'forward' logic)
        if (motor == Motor::LEFT) {
            printf("DEBUG: Motor reverse (LEFT now forward logic) - GPIO%u=0.0, GPIO%u=%.3f\n", pin1, pin2, -speed);
            setPwmDutyCycle(pin1, 0.0f);
            setPwmDutyCycle(pin2, -speed);
        } else {
            printf("DEBUG: Motor reverse (RIGHT now forward logic) - GPIO%u=%.3f, GPIO%u=0.0\n", pin1, -speed, pin2);
            setPwmDutyCycle(pin1, -speed);
            setPwmDutyCycle(pin2, 0.0f);
        }
    } else {
        // Stop (brake)
        printf("DEBUG: Motor stop - GPIO%u=0.0, GPIO%u=0.0\n", pin1, pin2);
        setPwmDutyCycle(pin1, 0.0f);
        setPwmDutyCycle(pin2, 0.0f);
    }
}
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

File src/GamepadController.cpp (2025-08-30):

#include "GamepadController.h"
#include "MotorController.h"
#include "AudioController.h"
#include "MosfetDriver.h"
#include <pico/cyw43_arch.h>
#include <pico/stdlib.h>
#include <stdio.h>
#include <cstring>
#include <cmath>

extern "C" {
    #include "sdkconfig.h"
}

namespace Exterminate {

// Static member definitions
struct uni_platform GamepadController::s_platform = {
    .name = "Exterminate Dalek Platform",
    .init = GamepadController::platformInit,
    .on_init_complete = GamepadController::platformOnInitComplete,
    .on_device_discovered = GamepadController::platformOnDeviceDiscovered,
    .on_device_connected = GamepadController::platformOnDeviceConnected,
    .on_device_disconnected = GamepadController::platformOnDeviceDisconnected,
    .on_device_ready = GamepadController::platformOnDeviceReady,
    .on_gamepad_data = nullptr,  // deprecated
    .on_controller_data = GamepadController::platformOnControllerData,
    .get_property = GamepadController::platformGetProperty,
    .on_oob_event = GamepadController::platformOnOobEvent,
    .device_dump = nullptr,  // optional
    .register_console_cmds = nullptr,  // optional
};

GamepadController& GamepadController::getInstance() {
    static GamepadController instance;
    return instance;
}

bool GamepadController::initialize() {
    if (m_initialized) {
        return true;
    }

    printf("GamepadController: Initializing BluePad32 system...\n");
    m_bluetoothState = BluetoothState::INITIALIZING;

    // Initialize CYW43 driver architecture (enables Bluetooth)
    if (cyw43_arch_init()) {
        printf("GamepadController: Failed to initialize cyw43_arch\n");
        m_bluetoothState = BluetoothState::ERROR;
        return false;
    }

    // Turn on LED during initialization
    cyw43_arch_gpio_put(CYW43_WL_GPIO_LED_PIN, 1);

    // Must be called before uni_init()
    uni_platform_set_custom(&s_platform);

    // Initialize BP32
    uni_init(0, nullptr);

    m_initialized = true;
    printf("GamepadController: BluePad32 initialized successfully\n");
    
    // Start LED update timer
    m_ledUpdateTimer.process = &GamepadController::ledUpdateTimerCallback;
    btstack_run_loop_set_timer(&m_ledUpdateTimer, 50); // Update every 50ms
    btstack_run_loop_add_timer(&m_ledUpdateTimer);
    
    return true;
}

void GamepadController::startEventLoop() {
    if (!m_initialized) {
        printf("GamepadController: Error - not initialized! Call initialize() first.\n");
        return;
    }

    printf("GamepadController: Starting BluePad32 event loop...\n");
    
    // This call blocks and does not return under normal operation
    btstack_run_loop_execute();
}

// Platform callback implementations
void GamepadController::setLEDController(SimpleLED::LEDStatusController* ledController) {
    m_ledController = ledController;
    updateLEDStatus(); // Update LED immediately when controller is set
}

void GamepadController::setMotorController(MotorController* motorController) {
    m_motorController = motorController;
    if (m_motorController) {
        printf("GamepadController: Motor controller connected for tank steering\n");
        printf("DEBUG: Motor controller initialized: %s\n", 
               m_motorController->isInitialized() ? "YES" : "NO");
    }
}

void GamepadController::setAudioController(AudioController* audioController) {
    m_audioController = audioController;
    if (m_audioController) {
        printf("GamepadController: Audio controller connected for sound effects\n");
        printf("DEBUG: Audio controller initialized: %s\n", 
               m_audioController->isInitialized() ? "YES" : "NO");
    }
}

void GamepadController::setMosfetDriver(MosfetDriver* mosfetDriver) {
    m_mosfetDriver = mosfetDriver;
    if (m_mosfetDriver) {
        printf("GamepadController: MOSFET driver registered\n");
    }
}

void GamepadController::updateLEDStatus() {
    if (!m_ledController) return;
    
    switch (m_bluetoothState) {
        case BluetoothState::INITIALIZING:
            m_ledController->setStatus(SimpleLED::LEDStatus::SLOW_BLINK);
            break;
        case BluetoothState::PAIRING:
            m_ledController->setStatus(SimpleLED::LEDStatus::BREATHING);
            break;
        case BluetoothState::CONNECTED:
            m_ledController->setStatus(SimpleLED::LEDStatus::SLOW_BLINK);
            break;
        case BluetoothState::PAIRED:
            m_ledController->setStatus(SimpleLED::LEDStatus::ON);
            break;
        case BluetoothState::ERROR:
            m_ledController->setStatus(SimpleLED::LEDStatus::FAST_BLINK);
            break;
    }
}

void GamepadController::ledUpdateTimerCallback(btstack_timer_source_t* timer) {
    (void)timer;
    
    GamepadController& instance = getInstance();
    
    // Update LED pattern
    if (instance.m_ledController) {
        instance.m_ledController->update();
    }
    
    // Reschedule timer
    btstack_run_loop_set_timer(&instance.m_ledUpdateTimer, 50); // 50ms = 20Hz update rate
    btstack_run_loop_add_timer(&instance.m_ledUpdateTimer);
}

void GamepadController::platformInit(int argc, const char** argv) {
    (void)argc;
    (void)argv;
    
    printf("GamepadController: Platform init callback\n");
}

void GamepadController::platformOnInitComplete() {
    printf("GamepadController: Platform initialization complete\n");

    // Start scanning and autoconnect to supported controllers
    uni_bt_start_scanning_and_autoconnect_unsafe();

    // Delete stored BT keys for fresh start (useful during development)
    uni_bt_del_keys_unsafe();

    // Turn off LED once init is done
    cyw43_arch_gpio_put(CYW43_WL_GPIO_LED_PIN, 0);

    // Update state to pairing mode
    getInstance().m_bluetoothState = BluetoothState::PAIRING;
    getInstance().updateLEDStatus();

    printf("GamepadController: Ready to accept gamepad connections\n");
    printf("GamepadController: All gamepad inputs will be logged to UART console\n");
}

uni_error_t GamepadController::platformOnDeviceDiscovered(bd_addr_t addr, const char* name, uint16_t cod, uint8_t rssi) {
    printf("GamepadController: Device discovered - Name: %s, RSSI: %d dBm\n", 
           name ? name : "Unknown", rssi);

    // Filter out keyboards as an example
    if (((cod & UNI_BT_COD_MINOR_MASK) & UNI_BT_COD_MINOR_KEYBOARD) == UNI_BT_COD_MINOR_KEYBOARD) {
        printf("GamepadController: Ignoring keyboard device\n");
        return UNI_ERROR_IGNORE_DEVICE;
    }

    return UNI_ERROR_SUCCESS;
}

void GamepadController::platformOnDeviceConnected(uni_hid_device_t* d) {
    printf("GamepadController: Device connected (ptr: %p, idx: %d)\n", 
           d, uni_hid_device_get_idx_for_instance(d));
    
    // Update state to connected (but not ready yet)
    getInstance().m_bluetoothState = BluetoothState::CONNECTED;
    getInstance().updateLEDStatus();
}
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

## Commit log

2025-08-01 Add MotorController class for DRV8833 motor control and update platform integration
2025-08-02 Add I2S PIO programs and audio conversion tools
    - Implemented I2S PIO programs for master and slave modes in `i2s.pio`, enabling audio data transmission and reception.
    - Created `test_audio.cpp` to verify audio system compilation and configuration.
    - Developed `audio_to_pcm_header.py` for converting audio files to PCM format C++ headers, facilitating direct I2S playback.
    - Added batch and PowerShell scripts (`convert_audio.bat`, `convert_audio.ps1`) for audio conversion automation.
    - Introduced `mp3_to_header.py` for converting MP3 files to C++ header files with embedded byte arrays.
    - Enhanced audio index generation for easy access to audio files in the project.
2025-08-05 Refactor CMakeLists.txt to enable UART output and remove blink.pio references from main.cpp
2025-08-05 Refactor audio system: Update sample rate, enhance logging, and restructure audio data handling
    - Changed AUDIO_SAMPLE_RATE from 22050 to 44100 in audio_index.h for improved audio quality.
    - Added detailed logging in AudioController and I2SController for better debugging and tracking of initialization processes.
    - Restructured audio data handling by generating separate source files for audio data implementations and audio index.
    - Implemented a new script to extract audio data definitions from headers, preventing multiple definition errors.
    - Updated audio_to_pcm_header.py to generate declarations only in header files and implementations in a single source file.
    - Created AudioData.cpp and A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
2025-08-06 Update project to support new audio features and SDK versions
    - Bump SDK version from 2.1.1 to 2.2.0 and picotool version from 2.1.1 to 2.2.0.
    - Change board type from 'pimoroni_pico_plus2_w_rp2350' to 'pimoroni_pico_plus2_rp2350'.
    - Include pico_extras_import.cmake for additional functionality.
    - Modify AudioController to support 32-bit PCM audio playback.
    - Update sample rate in AudioController configuration from 22050 Hz to 44100 Hz.
    - Refactor main.cpp to initialize GPIO and test I2S functionality.
    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
2025-08-07 Refactor I2S implementation and update audio controller configuration
    - Removed the old I2S.cpp and i2s.pio files, replacing them with a new implementation that follows updated design principles.
    - Updated the audio controller configuration in exterminate_platform.cpp to reflect new pin assignments and buffer settings.
    - Simplified main.cpp by removing manual I2S pin testing and integrating the new audio controller setup.
    - Enhanced logging for audio controller initialization and playback status.
    - Improved overall code organization and readability.
2025-08-08 Update I2S sample rate to 44.1kHz for improved audio playback compatibility
2025-08-09 Refactor LED subsystem and audio controller integration
    - Renamed LEDController to SimpleLED and updated file structure.
    - Simplified LED functionality to focus on PWM-based brightness control.
    - Removed legacy LEDController implementation and associated files.
    - Updated AudioController to maintain persistent buffer format.
    - Adjusted audio index to reflect reduced audio files.
    - Enhanced main application to initialize and control external LEDs based on audio intensity.
    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
2025-08-10 Add support for custom Pico Plus 2 XL W board with CYW43 integration
2025-08-10 Update board type for custom Pico Plus 2 configuration
2025-08-10 Refactor board configuration to use official Pimoroni Pico Plus 2 W RP2350 definition and remove custom board files for Pico Plus 2 XL W.
2025-08-10 Refactor audio system documentation for clarity and accuracy; update motor control pin assignments and configuration examples.
2025-08-12 Update documentation and code for Pimoroni Motor Shim integration; adjust GPIO pin assignments for audio and motor control.
2025-08-16 Implement LED status controller and gamepad functionality
    - Added LEDStatusController for managing LED states including breathing, blinking, and solid on/off.
    - Integrated LED status updates with GamepadController to reflect Bluetooth connection states.
    - Removed exterminate_platform.cpp and refactored initialization logic into main.cpp and GamepadController.
    - Created GamepadController class to handle Bluetooth gamepad connections and input logging.
    - Updated main.cpp to initialize and manage audio, motors, and LED status.
    - Added main_gamepad_test.cpp for testing gamepad functionality and LED status indications.
    - Configured btstack to assert on errors and adjusted SDK configuration for Bl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
    [GamepadController.cpp, SimpleLED.cpp, btstack_config.h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]
2025-08-16 Update documentation to reflect pico-extras I2S integration and resolve DMA channel conflicts; add troubleshooting guide and resource management details.
2025-08-16 Add motor controller integration for tank steering and update GPIO assignments
    - Introduced setMotorController method in GamepadController for tank-style steering.
    - Implemented processTankSteering method to handle gamepad input for motor control.
    - Updated MotorController initialization with detailed debug logging.
    - Changed external LED GPIO pins to avoid PWM conflicts with motor pins.
    - Adjusted motor pin assignments in main.cpp to match hardware wiring.
    - Added quick motor test during initialization to verify functionality.
    [GamepadController.cpp, MotorController.cpp, main.cpp]
2025-08-24 Add assembly documentation for fender mechanism and wiring integration
    - Step 7: Fender Mechanism & Skirt Integration
    - Detailed assembly instructions for fender cam mechanism, skirt attachment, and pushrod alignment.
    - Included parts list, tools required, preparation steps, and troubleshooting guide.
    - Step 8: Wiring Harness Integration & Electronics Mounting
    - Comprehensive guide for mounting audio amplifier, MOSFET driver, speaker, and drive motors.
    - Instructions for soldering Pico LiPo headers, Motor SHIM integration, and initial wiring for audio and power distribution.
    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
2025-08-27 Refactor motor control logic for left and right motors; update initialization in main and add configuration for DRV8833. Create new assembly documentation files.
2025-08-27 Adding models files
    [3006 MAX98357.step, 5648 MOSFET Driver.step, Gears v2.f3z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]
2025-08-30 Add MosfetDriver class and integrate with GamepadController for control via gamepad
2025-08-30 Update documentation and code comments to reflect removal of servo control; clarify motor driver references to Pimoroni Motor SHIM for Pico
2025-09-01 Update README and documentation to reflect removal of servo control; clarify hardware and software details for the Exterminate Dalek project.
